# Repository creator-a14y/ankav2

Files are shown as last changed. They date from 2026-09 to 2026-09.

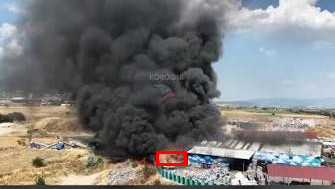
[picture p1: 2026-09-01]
yazılım/kart2-payload/arsiv/sahte_veriyle_test/alarmlar/yangin_20260901_140505.png

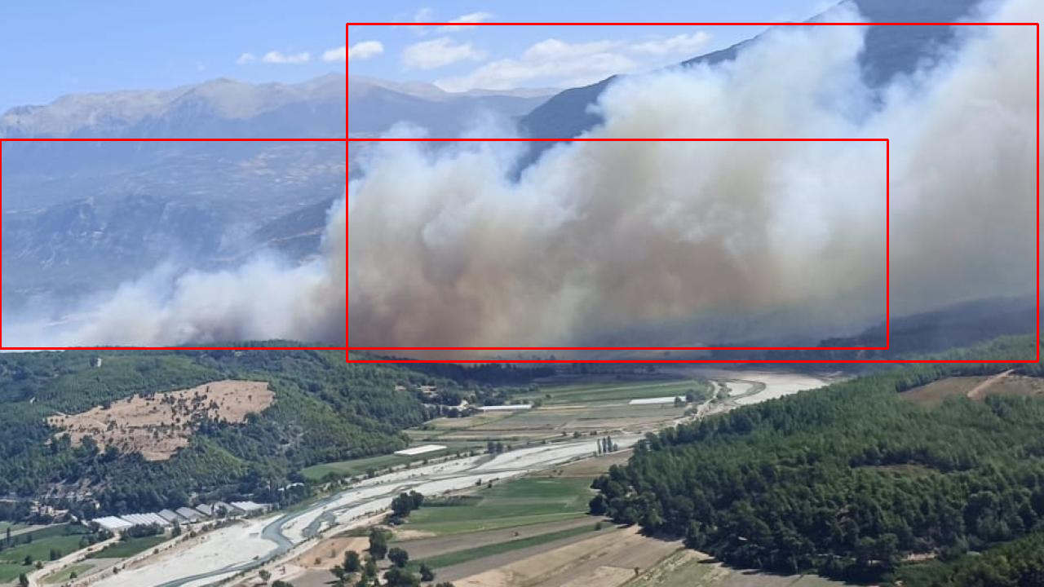
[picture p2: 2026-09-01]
yazılım/kart2-payload/arsiv/sahte_veriyle_test/alarmlar/yangin_20260901_140636.png

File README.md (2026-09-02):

# ANKA-v2 Zincir Düğüm ve Yangın Algılama İHA Projesi

ANKA-v2; otonom yangın algılama, termal görüntü işleme, GPS konum tespiti ve düğümler arası kablosuz (WiFi Mesh/Relay) veri aktarımı gerçekleştirmek üzere tasarlanmış modüler bir İHA ve haberleşme altyapısı projesidir.

Proje; arama-tarama ve yangın tespit görevlerini icra eden tespit düğümü ile bu verileri yer kontrol istasyonuna aktaran röle (zincir) düğümlerinden oluşur.

---

## Sistem Mimarisi ve Çalışma Prensibi

Sistem, uçuş kontrolü ve faydalı yük (payload) işlemlerini birbirinden ayıran bağımsız bir donanım mimarisine sahiptir:

* **Uçuş Kartı (Kart 1):** Uçuş kontrolcüsü olarak `flight32` kullanılmaktadır. Payloaddan (Kart 2) tamamen bağımsız çalışır. RC sinyali kesildiğinde motorları kesen Failsafe doğrulaması uçuş öncesinde sahada test edilir.
* **Payload Kartı (Kart 2):** Deneyap Kart v2 (ESP32-S3) üzerindedir. Termal kamera, kamera ve GPS modülünü yönetir.
* **Termal Tetikleme (Dinamik Eşik):** Adafruit MLX90640 termal kamerası ortam sıcaklığını taranan kare üzerinden okur. Maksimum sıcaklık mutlak tabanı ($45.0^{\circ}C$) ve ortam ortalamasından fark eşiğini ($20.0^{\circ}C$) aynı anda aştığında sistem yangın tespiti yapar.
* **Görsel ve Konum Verisi Toplama:** Termal tetikleme sağlandığında OV2640 kameradan JPEG fotoğraf çekilir ve Deneyap GPS/GLONASS modülünden anlık koordinatlar (GGA cümlesinden enlem ve boylam) okunur.
* **Zincir Aktarımı (Relay/Mesh):** Elde edilen veri paketi, zincirdeki bir sonraki düğümün Erişim Noktasına (AP) iletilir. Düğümler arası iletişim nöbetleşe yapıdadır; arka düğümden gelen veri forward edilir (relaylenir).

---

## Donanım Bileşenleri ve Maliyet Özeti (BOM)

Yüklenen `anka_maliyet.xlsx` dosyasındaki verilere göre 1 dron için tahmini bütçe tablosu aşağıdadır (Eylül 2026 piyasa verilerine göre):

| # | Kategori | Parça / Ürün | Kaynak / Referans | Adet | Birim (TL) | Toplam (TL) |
|---|---|---|---|:---:|:---:|:---:|
| **1** | Uçuş Kartı | Deneyap Kart v2 (ESP32-S3) | magaza.deneyapkart.org | 1 | 727 TL | 727 TL |
| **2** | Motor | 2205 2300KV Fırçasız Motor (CW+CCW set) | promodelhobby.com | 4 | 670 TL | 2.680 TL |
| **3** | ESC | 60A BLHeli_S 4-in-1 ESC (DShot, 30.5×30.5mm) | AliExpress TR | 1 | 1.446 TL | 1.446 TL |
| **4** | Pervane | 5045 Pervane seti (CW+CCW, 2 çift) | f1depo.com | 1 | 150 TL | 150 TL |
| **5** | Batarya | 4S 1500mAh 95C LiPo Batarya | robotzade.com | 1 | 3.216 TL | 3.216 TL |
| **6** | BEC | 5V 3A UBEC (LiPo→5V) | robotzade.com / robotsepeti.com | 1 | 280 TL | 280 TL |
| **7** | IMU | MPU9250 IMU Modülü (I2C, 9 eksen) | amazon.com.tr | 1 | 400 TL | 400 TL |
| **8** | Kumanda / Alıcı | Flysky FS-i6X Kumanda + FS-iA6B Alıcı seti | promodelhobby.com | 1 | 4.279 TL | 4.279 TL |
| **9** | Şasi | 5" FPV Quadcopter Çerçeve (210-250mm, karbon) | Piyasa tahmini | 1 | 800 TL | 800 TL |
| **10** | Güç | XT60 LiPo Konnektörü (dişi+erkek çift) | Genel piyasa | 1 | 75 TL | 75 TL |
| **11** | Bağlantı | Kablo, vida, standoff, ısıyla küçülen boru | Genel piyasa | 1 | 150 TL | 150 TL |
| **12** | Payload Kartı | Deneyap Kart v2 (ESP32-S3) | magaza.deneyapkart.org | 1 | 727 TL | 727 TL |
| **13** | Kamera | Deneyap Kamera (OV2640, FPC) | robolinkmarket.com | 1 | 715 TL | 715 TL |
| **14** | Termal Kamera | MLX90640 Termal Kamera (32×24, I2C) | direnc.net | 1 | 3.303 TL | 3.303 TL |
| **15** | GPS | Deneyap GPS/GLONASS Modülü (Quectel L86) | magaza.deneyapkart.org | 1 | 900 TL | 900 TL |
| **16** | Bağlantı | I2C Bağlantı Kablosu (10cm, 2 adet) | Modül ile gelebilir | 2 | 30 TL | 60 TL |
| **17** | Programlama | USB Kablo (Type-C, programlama) | Genel piyasa | 2 | 100 TL | 200 TL |
| **18** | Şarj Aleti | LiPo Şarj Aleti (dengeli şarj, 4S uyumlu) | Genel piyasa | 1 | 700 TL | 700 TL |
| **TOPLAM** | | | | | | **20.808 TL** |

---

## Projenin Amacı

ANKA-v2 projesinin temel amacı; ormanlık, dağlık veya geniş karasal alanlarda meydana gelebilecek yangınları **otonom olarak erken aşamada tespit etmek**, taranan bölgedeki anlık termal/görsel verileri ve GPS koordinatlarını **GSM (hücresel ağ) veya internet altyapısına ihtiyaç duymadan**, dronlar arası kurulan kablosuz zincir/röle (Mesh/Relay) haberleşme ağı üzerinden **Yer Kontrol İstasyonuna kesintisiz ve hızlı bir şekilde aktarmaktır**.

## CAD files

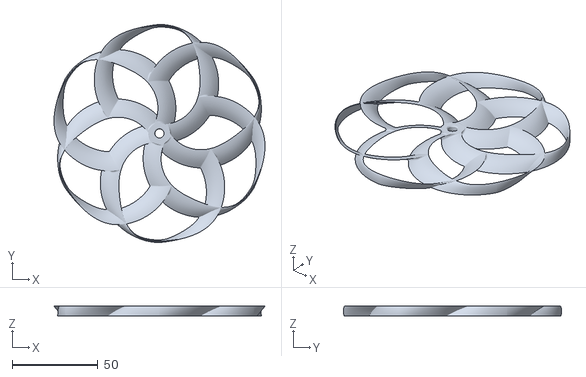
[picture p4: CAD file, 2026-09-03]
3d models/Hex-Toroidal_50x3_CCW v1.stl
122.9 x 127.0 x 6.01

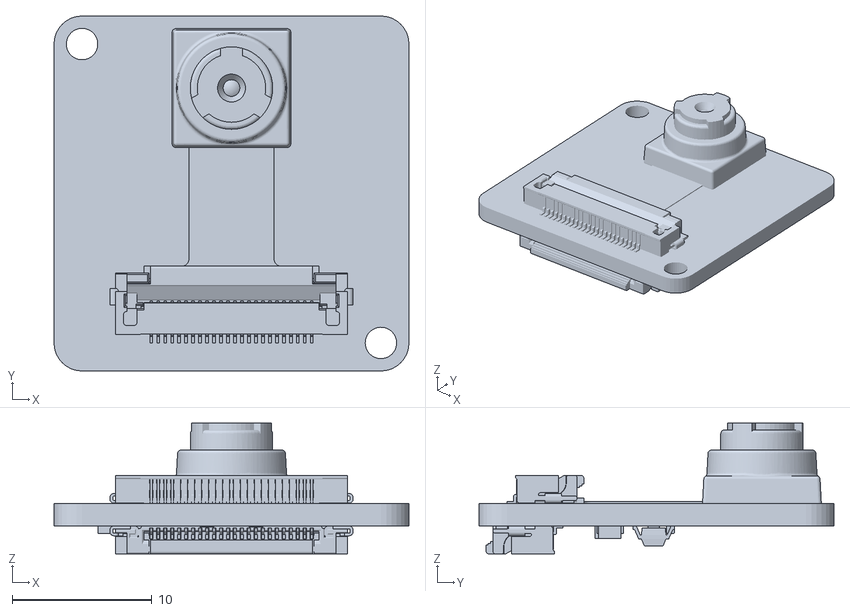
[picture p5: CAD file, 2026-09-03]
3d models/deneyapkamera.stl
25.4 x 25.4 x 9.37

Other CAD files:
3d models/Hex-Toroidal_50x3_CW v1.stl

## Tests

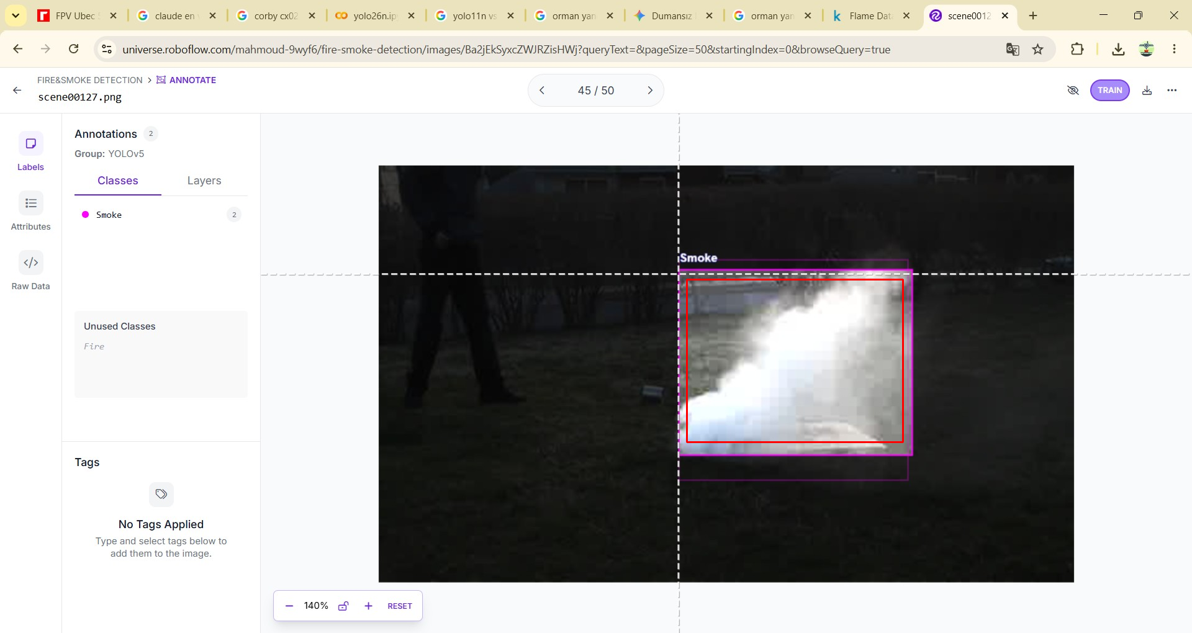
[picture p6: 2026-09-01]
yazılım/kart2-payload/arsiv/sahte_veriyle_test/alarmlar/yangin_20260901_143512.png

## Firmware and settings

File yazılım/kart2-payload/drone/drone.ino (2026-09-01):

/*
  ZINCIR DUGUM FIRMWARE ISKELETI - Deneyap Kart V2 (ESP32-WROVER-E, PSRAM'li)

  Her dugum: kendi AP'sini kurar (arkadaki baglanir) + onundeki dugumun AP'sine
  STA baglanir (veriyi ileri tasir). Akis: tespit eden dron -> role(ler) -> yer ist.

  Bu surumde DOLDURULDU:
   - termalTetik()  -> Adafruit MLX90640 (I2C), DINAMIK esik: ortam ortalamasindan
                       fark + mutlak taban (guneste isinan yuzeyleri eler)
   - foto cekme     -> esp_camera (OV2640, JPEG)
  HALA TODO:
   - gpsOku()       -> GPS modulu baglaninca
   - KAMERA PIN HARITASI -> Deneyap kamera orneginden kopyalanacak (asagida)
   - FAILSAFE DOGRULAMASI: bu dosya uctan bagimsiz calisir (flight32 ayri kartta).
     Uçuş kartinin RC sinyali kesilince motorlari kestigi SAHADA test edilmeli -
     ilk ucustan once atlanmamasi gereken guvenlik adimi.

  !! DERLENIP TEST EDILMEDI !! Deneyap board paketi + kutuphaneler + donanim gerekir.
  Gerekli kutuphaneler (Arduino Library Manager):
    - "Adafruit MLX90640"  (+ bagimliliklarini kabul et)
    - esp_camera: Deneyap/ESP32 arduino core ile birlikte gelir (ayri kurulum yok)
*/

#include <WiFi.h>
#include "esp_camera.h"
#include <Wire.h>
#include <Adafruit_MLX90640.h>
#include "Deneyap_GPSveGLONASSkonumBelirleyici.h"   // Deneyap GPS (I2C), Library Manager'dan kur

// ==================== HER DUGUMDE DEGISEN AYARLAR ====================
const char* UPLINK_SSID = "ZINCIR_1";          // ONUMDEKI (GS'e yakin) dugumun AP adi
const char* UPLINK_PASS = "12345678";
const char* MY_AP_SSID  = "ZINCIR_2";          // BENIM AP adim (arkadaki buna baglanir)
const char* MY_AP_PASS  = "12345678";
IPAddress   MY_AP_IP(192, 168, 20, 1);         // HER DUGUMDE FARKLI subnet
// ====================================================================

const uint16_t PORT = 5000;

// --- DINAMIK TERMAL ESIK ---
// Guneste isinan cati/kaya/asfalt gibi yuzeyler tek basina 60C'yi asabilir ama
// CEVRESIYLE BIRLIKTE isinir (fark kucuk kalir). Gercek yangin/sicak nokta,
// cevresinden KESKIN sekilde farklidir. Iki sart AYNI ANDA saglanmali:
//   1) maks sicaklik, kare ORTALAMASINDAN en az TERMAL_FARK_ESIK derece yuksek
//   2) maks sicaklik, mutlak taban TERMAL_TABAN'i gecmis (cok soguk gunde
//      relatif fark tek basina yaniltmasin diye guvenlik payi)
const float TERMAL_TABAN     = 45.0;   // °C, bunun altinda hicbir zaman tetiklemez
const float TERMAL_FARK_ESIK = 20.0;   // °C, ortam ortalamasindan fark


// ============ KAMERA PIN HARITASI (Deneyap Kart 1A v2 - ESP32-S3, FPC soketi) ============
// V2 core kamera pinlerini CAMD2..CAMD9, CAMSD, CAMSC, CAMXC, CAMPC, CAMV, CAMH
// sabitleriyle KENDISI tanimlar -> otoriter kaynak. GPIO'lar yorumda.
// (Not: eski Deneyap Kart tablosu (D5/A2/DAC...) V2'ye UYMUYOR.)
#define CAM_PIN_D0     CAMD2   // GPIO41
#define CAM_PIN_D1     CAMD3   // GPIO2
#define CAM_PIN_D2     CAMD4   // GPIO1
#define CAM_PIN_D3     CAMD5   // GPIO42
#define CAM_PIN_D4     CAMD6   // GPIO40
#define CAM_PIN_D5     CAMD7   // GPIO38
#define CAM_PIN_D6     CAMD8   // GPIO17
#define CAM_PIN_D7     CAMD9   // GPIO15
#define CAM_PIN_SIOD   CAMSD   // GPIO4  (SCCB veri)
#define CAM_PIN_SIOC   CAMSC   // GPIO5  (SCCB clock)
#define CAM_PIN_XCLK   CAMXC   // GPIO16
#define CAM_PIN_PCLK   CAMPC   // GPIO39
#define CAM_PIN_VSYNC  CAMV    // GPIO6
#define CAM_PIN_HREF   CAMH    // GPIO7
#define CAM_PIN_PWDN   -1
#define CAM_PIN_RESET  -1
// ================================================================================

Adafruit_MLX90640 mlx;
GPS konum;                                        // Deneyap GPS. 'gps' ismi kutuphanede kullanildigi icin 'konum' dedik
float termalKare[32 * 24];                      // 768 piksel
WiFiServer server(PORT);


void kameraInit() {
  camera_config_t c;
  c.ledc_channel = LEDC_CHANNEL_0;
  c.ledc_timer   = LEDC_TIMER_0;
  c.pin_d0 = CAM_PIN_D0;  c.pin_d1 = CAM_PIN_D1;  c.pin_d2 = CAM_PIN_D2;  c.pin_d3 = CAM_PIN_D3;
  c.pin_d4 = CAM_PIN_D4;  c.pin_d5 = CAM_PIN_D5;  c.pin_d6 = CAM_PIN_D6;  c.pin_d7 = CAM_PIN_D7;
  c.pin_xclk  = CAM_PIN_XCLK;
  c.pin_pclk  = CAM_PIN_PCLK;
  c.pin_vsync = CAM_PIN_VSYNC;
  c.pin_href  = CAM_PIN_HREF;
  c.pin_sccb_sda = CAM_PIN_SIOD;   // eski core'da isim: pin_sscb_sda (derleme hatasi olursa degistir)
  c.pin_sccb_scl = CAM_PIN_SIOC;   // eski core'da isim: pin_sscb_scl
  c.pin_pwdn  = CAM_PIN_PWDN;
  c.pin_reset = CAM_PIN_RESET;
  c.xclk_freq_hz = 20000000;
  c.pixel_format = PIXFORMAT_JPEG;              // sikistirilmis -> gonderime uygun
  c.frame_size   = FRAMESIZE_VGA;               // 640x480, zincirde hizli tasinir
  c.jpeg_quality = 12;                          // 10-15 (kucuk sayi = daha kaliteli/buyuk)
  c.fb_count     = 2;                           // PSRAM var (WROVER)
  c.fb_location  = CAMERA_FB_IN_PSRAM;          // eski core'da yoksa bu satiri sil
  c.grab_mode    = CAMERA_GRAB_LATEST;          // eski core'da yoksa bu satiri sil

  if (esp_camera_init(&c) != ESP_OK)
    Serial.println("HATA: kamera baslatilamadi (pin haritasini kontrol et).");
}

// Kare 32 genislik x 24 yukseklik olarak duzlestirilmis (satir-satir, row-major)
const int TERMAL_GENISLIK = 32;
const int TERMAL_YUKSEKLIK = 24;

bool termalTetik() {
  if (mlx.getFrame(termalKare) != 0) return false;   // okuma hatasi

  float toplam = 0;
  for (int i = 0; i < 768; i++) toplam += termalKare[i];
  float ortalama = toplam / 768.0;

  // Tekil piksel yerine 3x3 blok ortalamasi al - tekil parazit/dead pixel
  // yanlis tetiklemeyi (spurious trigger) onler. En sicak 3x3 blok "maks" sayilir.
  float maksBlok = -1000;
  for (int y = 0; y <= TERMAL_YUKSEKLIK - 3; y++) {
    for (int x = 0; x <= TERMAL_GENISLIK - 3; x++) {
      float blokToplam = 0;
      for (int dy = 0; dy < 3; dy++)
        for (int dx = 0; dx < 3; dx++)
          blokToplam += termalKare[(y + dy) * TERMAL_GENISLIK + (x + dx)];
      float blokOrt = blokToplam / 9.0;
      if (blokOrt > maksBlok) maksBlok = blokOrt;
    }
  }
  float fark = maksBlok - ortalama;

  // iki sart AYNI ANDA: mutlak taban VE ortamdan keskin fark
  return (maksBlok >= TERMAL_TABAN) && (fark >= TERMAL_FARK_ESIK);
}

String gpsOku() {
  // Deneyap GPS'ten konum. GGA cumlesi konum icerir. Fix yoksa 0.0,0.0 doner.
  if (konum.readGPS(GGA)) {
    double lat = konum.readLocationLat();
    double lng = konum.readLocationLng();
    return String(lat, 6) + "," + String(lng, 6);
  }
  return "0.0,0.0";   // fix yok / okuma basarisiz (ic mekanda normal)
}

// Onumdeki dugume (gateway) paketi gonder
void ileriGonder(uint8_t* foto, size_t boyut, String gps) {
  WiFiClient c;
  if (c.connect(WiFi.gatewayIP(), PORT)) {
    c.print("GPS:"); c.print(gps);   c.print("\n");
    c.print("LEN:"); c.print(boyut); c.print("\n");
    if (foto && boyut) c.write(foto, boyut);
    c.stop();
    Serial.println("Ileri gonderildi.");
  } else {
    Serial.println("HATA: uplinke baglanilamadi.");
  }
}

// Arkadan gelen paketi aynen ileri aktar (blok bazli, byte-byte degil - overhead'i dusurur)
void relayle(WiFiClient& arka) {
  WiFiClient c;
  if (!c.connect(WiFi.gatewayIP(), PORT)) {
    Serial.println("HATA: relay icin uplinke baglanilamadi, paket dusuyor.");
    arka.stop();
    return;
  }
  uint8_t buf[256];
  while (arka.connected() || arka.available()) {
    size_t hazir = arka.available();
    if (hazir) {
      size_t okunan = arka.read(buf, min(hazir, sizeof(buf)));
      c.write(buf, okunan);
    } else if (!arka.connected()) {
      break;
    }
  }
  c.stop();
  arka.stop();
}

// Uplink baglantisini bloklamadan kontrol/yeniden dener (setup'ta sonsuz beklemeyi onler)
unsigned long sonUplinkDenemesi = 0;
const unsigned long UPLINK_DENEME_ARALIGI_MS = 3000;

void uplinkKontrolEt() {
  if (WiFi.status() == WL_CONNECTED) return;
  unsigned long simdi = millis();
  if (simdi - sonUplinkDenemesi < UPLINK_DENEME_ARALIGI_MS) return;  // henuz erken, tekrar deneme
  sonUplinkDenemesi = simdi;
  Serial.println("Uplink baglantisi yok, tekrar deneniyor...");
  WiFi.begin(UPLINK_SSID, UPLINK_PASS);   // non-blocking; sonucu bir sonraki kontrolde gorulur
}

void setup() {
  Serial.begin(115200);

  // Termal (Deneyap I2C konnektoru - varsayilan SDA/SCL)
  Wire.begin();
  Wire.setClock(400000);                              // 400kHz Fast Mode - termal okumayi hizlandirir
  if (!mlx.begin(0x33, &Wire)) Serial.println("HATA: MLX90640 bulunamadi.");
  mlx.setMode(MLX90640_CHESS);
  mlx.setResolution(MLX90640_ADC_18BIT);
  mlx.setRefreshRate(MLX90640_4_HZ);

  // GPS (ayni I2C hatti, adres 0x2F - termal 0x33 ile cakismaz)
  if (!konum.begin()) Serial.println("HATA: GPS bulunamadi.");

  // Kamera
  kameraInit();

  // Kamera warm-up: DMA tamponundaki olasi "bayat" ilk kareyi at (esp_camera_fb_get
  // sensor acilisinda/ilk karede eski/gecersiz veri dondurebilir)
  camera_fb_t* isinma = esp_camera_fb_get();
  if (isinma) esp_camera_fb_return(isinma);

  // WiFi zincir (AP + STA) - AP HER ZAMAN acilir, uplink olmasa bile arkadaki dugum baglanabilsin
  WiFi.mode(WIFI_AP_STA);
  WiFi.softAPConfig(MY_AP_IP, MY_AP_IP, IPAddress(255, 255, 255, 0));
  WiFi.softAP(MY_AP_SSID, MY_AP_PASS);
  WiFi.begin(UPLINK_SSID, UPLINK_PASS);

  // Uplink'i EN FAZLA ~5sn bekle, sonra bloklamadan devam et - server.begin() her turlu calisir
  unsigned long baslangic = millis();
  while (WiFi.status() != WL_CONNECTED && millis() - baslangic < 5000) {
    delay(200);
    Serial.print(".");
  }
  if (WiFi.status() == WL_CONNECTED) {
    Serial.print("\nUplink OK. Ileri adres: ");
    Serial.println(WiFi.gatewayIP());
  } else {
    Serial.println("\nUplink henuz yok, AP modunda devam ediliyor (loop icinde tekrar denenecek).");
  }

  server.begin();   // uplink olsun olmasin BASLAR - arkadaki dugumu asla bekletmez
}

void loop() {
  uplinkKontrolEt();   // uplink kopmussa bloklamadan periyodik yeniden dener

  // A) TESPIT: yangin gordu mu -> foto cek -> ileri gonder
  if (termalTetik()) {
    camera_fb_t* fb = esp_camera_fb_get();
    if (fb) {
      String gps = gpsOku();
      ileriGonder(fb->buf, fb->len, gps);
      esp_camera_fb_return(fb);                 // ONEMLI: buffer'i geri ver
    } else {
      Serial.println("HATA: foto alinamadi.");
    }
    delay(2000);                                // ayni yangin icin spam'i onle
  }

  // B) RELAY: arkadaki dugumden veri geldiyse ileri tasi
  WiFiClient arka = server.available();
  if (arka) relayle(arka);
}

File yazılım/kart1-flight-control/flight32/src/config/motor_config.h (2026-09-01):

/**
 * @file motor_config.h
 * @brief Configuration settings for motor control, including DShot protocol parameters and motor pin assignments.
 * @author Wastl Kraus - derdoktor667
 * @license MIT
 */

#pragma once

#include <cstdint>
#include <DShotRMT.h>
#include "../utils/system_constants.h"


// --- Motor Task Configuration ---
constexpr uint32_t MOTOR_TASK_STACK_SIZE = 4096;
constexpr uint8_t MOTOR_TASK_PRIORITY = 3;
constexpr int8_t MOTOR_TASK_CORE = 0;
constexpr uint8_t MOTOR_TASK_DELAY_MS = 10;
constexpr uint8_t NUM_MOTORS = 4;
constexpr uint8_t MOTOR_PIN_FR = 5;   // GPIO5  (Deneyap A1)
constexpr uint8_t MOTOR_PIN_RL = 6;   // GPIO6  (Deneyap A2)
constexpr uint8_t MOTOR_PIN_FL = 7;   // GPIO7  (Deneyap A3)
constexpr uint8_t MOTOR_PIN_RR = 15;  // GPIO15 (Deneyap A4)
constexpr dshot_mode_t DSHOT_PROTOCOL = DSHOT300;
constexpr int MOTOR_PINS_ARRAY[NUM_MOTORS] = {MOTOR_PIN_RR, MOTOR_PIN_FR, MOTOR_PIN_RL, MOTOR_PIN_FL};
constexpr uint16_t MOTOR_MIN_THROTTLE_RAW = 48;
constexpr uint16_t MOTOR_MAX_THROTTLE_RAW = 2047;
constexpr uint16_t THROTTLE_DEADZONE_THRESHOLD = 100; // Raw RC value below which motors are disarmed/stopped

enum class DshotProtocolIndex : uint8_t
{
    DSHOT150 = 0,
    DSHOT300 = 1,
    DSHOT600 = 2,
    DSHOT1200 = 3
};

constexpr uint8_t FIRST_MOTOR_INDEX = 0;

constexpr uint8_t MOTOR_INDEX_RR = 0; // Rear Right
constexpr uint8_t MOTOR_INDEX_FR = 1; // Front Right
constexpr uint8_t MOTOR_INDEX_RL = 2; // Rear Left
constexpr uint8_t MOTOR_INDEX_FL = 3; // Front Left

// --- Motor Protocol Settings ---
constexpr const char *NVS_KEY_MOTOR_PROTOCOL = "motor.proto";
constexpr uint8_t DEFAULT_MOTOR_PROTOCOL = static_cast<uint8_t>(DshotProtocolIndex::DSHOT300); // Corresponds to DSHOT300
extern const char *const DSHOT_PROTOCOL_STRINGS[];
extern const uint8_t NUM_DSHOT_PROTOCOLS;

// Normalized throttle values (0.0 to 1.0)
constexpr float MIN_NORMALIZED_THROTTLE = 0.0f;
constexpr float MAX_NORMALIZED_THROTTLE = 1.0f;

// Throttle percentage constants (0.0 to 100.0)
constexpr float MAX_THROTTLE_PERCENTAGE = CPU_PERCENTAGE_FACTOR;

// --- BLHeli_S 1-Wire Passthrough Constants ---
constexpr uint16_t sil_t_reset_us = 650;  // Reset time
constexpr uint16_t sil_t_delay_us = 10;   // Delay after reset
constexpr uint16_t sil_half_bit_delay_us = 14; // Half bit delay (critical timing)
constexpr uint16_t sil_t_start_us = 5;    // Start bit delay
constexpr uint16_t sil_t_stop_us = 10;    // Stop bit delay
constexpr uint16_t sil_t_byte_us = 200;   // Byte transmission delay

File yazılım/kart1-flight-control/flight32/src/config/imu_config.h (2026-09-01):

/**
 * @file imu_config.h
 * @brief Configuration settings for the IMU sensor, including task parameters, I2C settings, and LPF bandwidth.
 * @author Wastl Kraus - derdoktor667
 * @license MIT
 */

#pragma once

#include <cstdint>


// --- IMU Task Configuration ---
constexpr uint32_t IMU_TASK_STACK_SIZE = 4096;
constexpr uint8_t IMU_TASK_PRIORITY = 5;
constexpr int8_t IMU_TASK_CORE = 1;
constexpr uint8_t IMU_TASK_DELAY_MS = 10;
constexpr uint8_t MPU6050_I2C_SDA = 47;   // Deneyap V2 I2C SDA (eski: 21)
constexpr uint8_t MPU6050_I2C_SCL = 21;   // Deneyap V2 I2C SCL (eski: 22 -> S3'te yok)
constexpr uint32_t MPU6050_I2C_CLOCK_SPEED = 400000;
constexpr uint8_t MPU6050_I2C_ADDRESS = 0x68;     // usually 0x68
constexpr uint8_t MPU6050_FIFO_BUFFER_SIZE = 128; // Size of the MPU6050 FIFO buffer
constexpr uint8_t MPU6050_INT_PIN = 4;            // GPIO for MPU6050 Interrupt pin
static constexpr bool IMU_DMP_ENABLED_DEFAULT = true;   // Default setting for enabling the Digital Motion Processor (DMP)

// --- IMU Protocol Configuration ---
enum class ImuType : uint8_t
{
    MPU6050 = 0,
    NONE = 255
};

constexpr const char *NVS_KEY_IMU_TYPE = "imu.type";
constexpr ImuType DEFAULT_IMU_TYPE = ImuType::MPU6050;

enum class ImuGyroRangeIndex : uint8_t
{
    GYRO_RANGE_250DPS = 0,
    GYRO_RANGE_500DPS = 1,
    GYRO_RANGE_1000DPS = 2,
    GYRO_RANGE_2000DPS = 3
};

enum class ImuAccelRangeIndex : uint8_t
{
    ACCEL_RANGE_2G = 0,
    ACCEL_RANGE_4G = 1,
    ACCEL_RANGE_8G = 2,
    ACCEL_RANGE_16G = 3
};

enum class ImuLpfBandwidthIndex : uint8_t
{
    LPF_256HZ_N_0MS = 0,
    LPF_188HZ_N_2MS = 1,
    LPF_98HZ_N_3MS = 2,
    LPF_42HZ_N_5MS = 3,
    LPF_20HZ_N_10MS = 4,
    LPF_10HZ_N_13MS = 5,
    LPF_5HZ_N_18MS = 6
};

// --- IMU LPF Bandwidth Configuration ---
constexpr const char *NVS_KEY_IMU_LPF_BANDWIDTH = "imu.lpf_bw";
constexpr const char *NVS_KEY_IMU_DMP_EN = "imu.dmp_en";
constexpr uint8_t DEFAULT_IMU_LPF_BANDWIDTH = static_cast<uint8_t>(ImuLpfBandwidthIndex::LPF_256HZ_N_0MS); // Corresponds to LPF_256HZ_N_0MS
extern const char *const IMU_LPF_BANDWIDTH_STRINGS[];
extern const uint8_t NUM_IMU_LPF_BANDWIDTHS;

// --- Sensor ---

constexpr uint16_t SENSOR_POWER_UP_DELAY_MS = 100;



// Mahony Filter

constexpr float MAHONY_SAMPLE_RATE_HZ = 100.0f; // Mahony filter sample rate in Hz



// Scaling factors for raw IMU data

constexpr float ACCEL_G_TO_MG_FACTOR = 1000.0f; // Convert G to milli-G (mg)

constexpr float GYRO_DEGS_TO_MDEGS_FACTOR = 1000.0f; // Convert deg/s to milli-deg/s (mdeg/s)



// --- IMU General Constants ---

constexpr uint8_t NUM_AXES = 3;
constexpr float MSP_ACCEL_SCALING_FACTOR = 512.0f; // 1G = 512 (approx)
constexpr float MSP_GYRO_SCALING_FACTOR = 4.0f;    // 1 deg/s = 4 (approx)
